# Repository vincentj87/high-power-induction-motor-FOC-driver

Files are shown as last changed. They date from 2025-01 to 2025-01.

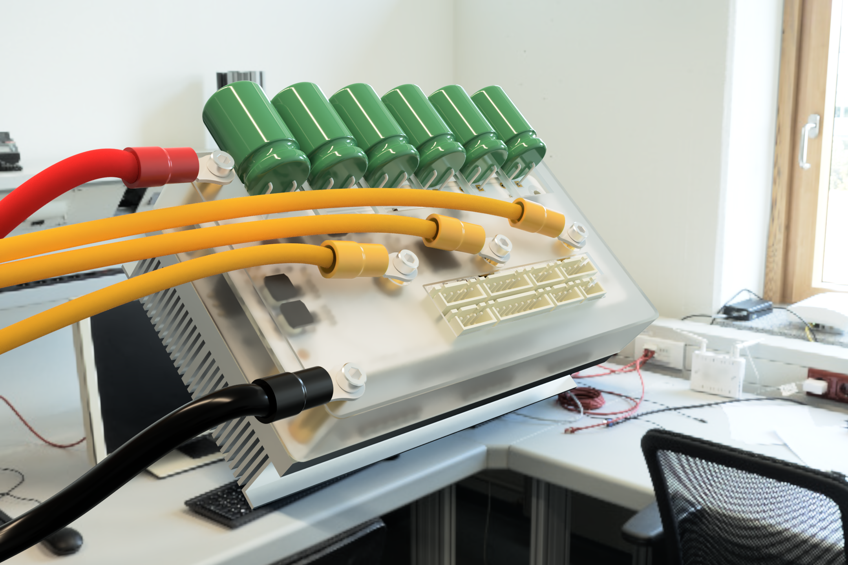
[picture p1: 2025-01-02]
Doc/49a2ab7d-ae84-4829-adb7-912b41497d58.PNG

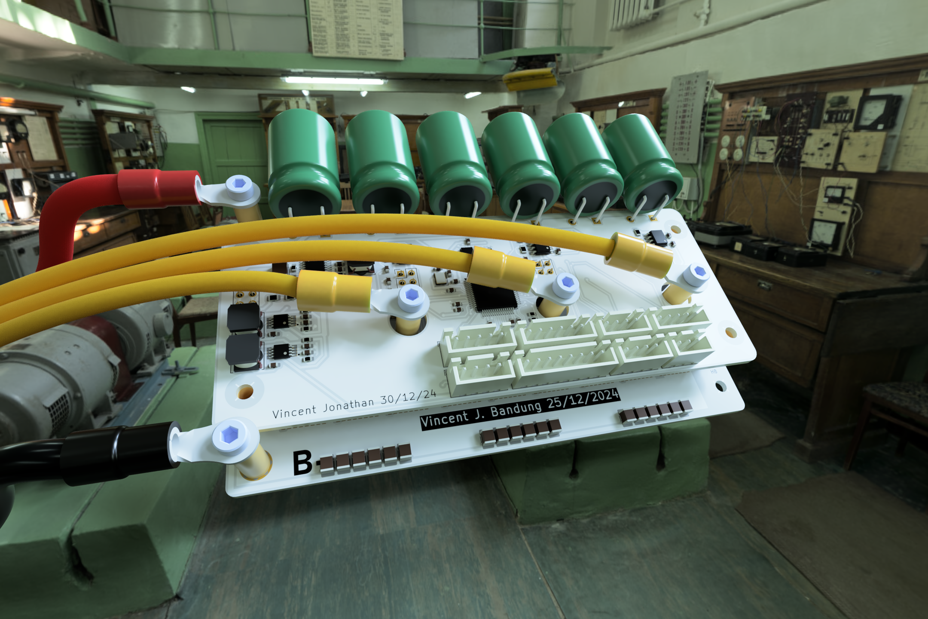
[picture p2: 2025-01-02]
Doc/Untitled_2024-Dec-31_10-01-42AM-000_CustomizedView10278926795.png

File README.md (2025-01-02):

49a2ab7d-ae84-4829-adb7-912b41497d58

# High Power BLDC Motor Driver with Field-Oriented Control (FOC)
This repository contains an ongoing project for a high-power BLDC motor driver, capable of handling up to 92V. The motor driver implements the **Field-Oriented Control (FOC)** commutation method for enhanced efficiency. Additionally, it integrates **Maximum Torque Per Amp (MTPA)** control to optimize performance.

## Key Features:
- **Field-Oriented Control (FOC)**: For efficient commutation, reducing power losses and improving motor performance.
- **MTPA (Maximum Torque Per Amp)**: Optimizes motor operation for maximum torque output with minimal current draw.
- **High Power Handling**: Supports up to 92V for heavy-duty applications.
  
## Components:
All components included in the Bill of Materials (BOM) file are readily available through **LCSC** for easy sourcing.

## PCB Design:
- The controller PCB is designed for a **2-layer FR4** board.
- The MOSFET array is implemented on a **1-layer aluminum PCB** to maximize heat dissipation, particularly under heavy load conditions.

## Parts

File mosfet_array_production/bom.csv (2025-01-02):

Designator | Footprint | Quantity | Value | LCSC Part #
C1, C10, C11, C12, C13, C14, C15, C16, C17, C18, C2, C3, C4, C5, C6, C7, C8, C9 | 1210 | 18 | 4.7uF_100V | C697607
C19, C22, C24 | 0402 | 3 | 2.2uF | C2176814
C20, C21, C23 | 0402 | 3 | 1nF | C106205
H1, H2, H3, H5, H6 | PEM_SMTSO-M3-6ET | 5 | SMTSO-M3-6ET | C30182787
H10, H11, H4, H7 | PEM_SMTSO-M3-6ET | 4 | SMTSO-M3-6ET | C2916370
J1, J2, J3, J4 | PinHeader_2x03_P2.54mm_Vertical_SMD | 4 | header 2x3 | C192301
Q1, Q10, Q11, Q12, Q13, Q14, Q15, Q16, Q17, Q18, Q2, Q3, Q4, Q5, Q6, Q7, Q8, Q9 | Infineon_PG-HSOF-8-1 | 18 | IRLML6244 | C697607
R1, R11, R12, R13, R2, R3, R6, R7, R8 | 2512 | 9 | 0.0005R | C5119469
R4, R5, R9 | 0402 | 3 | 10k | C60490
TH1, TH2, TH3 | 0402 | 3 | Thermistor_NTC | C2689808
U1, U2, U3 | TSSOP-8_4.4x3mm_P0.65mm | 3 | INA240A1PW | C93965

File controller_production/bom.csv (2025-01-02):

Designator | Footprint | Quantity | Value | LCSC Part #
C1, C2 | 0603 | 2 | 20pF | C5137583
C10, C11, C12, C15, C17, C20, C22, C25, C26, C27, C28, C3, C39, C4, C40, C8, C9 | 0603 | 17 | 2.2uf | C2835569
C13, C14, C16, C21, C24, C29, C30, C31, C32, C41, C5 | 0603 | 11 | 100nF | C14663
C18 | 0603 | 1 | 10nF | C100042
C19 | 1812 | 1 | 4.7uF 100V | C2831628
C23 | 0603 | 1 | 22uF_16V | C59461
C33, C36, C38 | 0603 | 3 | 1nF | C342905
C34, C35, C37 | 0603 | 3 | 15nF | C527994
C42, C43, C44, C45, C46, C47 | CP_Radial_D16.0mm_P7.50mm | 6 | 470uF_100V | C365811
C6, C7 | 0603 | 2 | 2.2uf | C2167658
D1, D3 | 0603 | 2 | LED | C3291493
D2 | 0603 | 1 | LED | C496821
J1, J2, J3, J4 | PinHeader_2x03_P2.54mm_Vertical | 4 | Conn_02x03_Odd_Even | C32713304
J10, J11 | JST_XH_B5B-XH-A_1x05_P2.50mm_Vertical | 2 | Conn_01x05 | C157991
J12, J5, J6 | JST_XH_B4B-XH-A_1x04_P2.50mm_Vertical | 3 | Conn_01x04 | C144395
J7 | JST_XH_B6B-XH-A_1x06_P2.50mm_Vertical | 1 | Conn_01x06 | C144397
J8 | JST_XH_B8B-XH-A_1x08_P2.50mm_Vertical | 1 | Conn_01x08 | C157972
J9 | JST_XH_B3B-XH-A_1x03_P2.50mm_Vertical | 1 | Conn_01x03 | C144394
JP1 | SolderJumper-2_P1.3mm_Open_TrianglePad1.0x1.5mm | 1 | DNP | DNP
JP2, JP4, JP5, JP6, JP8 | SolderJumper-2_P1.3mm_Open_TrianglePad1.0x1.5mm | 5 | DNP
JP3 | SolderJumper-2_P1.3mm_Open_TrianglePad1.0x1.5mm | 1 | Jumper_2_Open
L1, L2, L3 | L_TDK_VLS6045EX_VLS6045AF | 3 | 100uH 1A | C2042037
R1 | 0603 | 1 | 402k | C705774
R10, R12, R14, R8 | 0805 | 4 | 56k 0.5W | C441990
R11, R13, R15, R9 | 0805 | 4 | 2.2k | C2078022
R16, R17, R18, R19 | 0603 | 4 | 220R | C351666
R2, R5, R7 | 0603 | 3 | 10k | C98220
R20, R21, R22 | 0603 | 3 | 2.2k | C2078022
R23 | 0603 | 1 | 100R | C855560
R3 | 0603 | 1 | 2k | C103396
R4, R6 | 0603 | 2 | 33k | C163907
U1 | LQFP-64_10x10mm_P0.5mm | 1 | STM32F405RGTx | C15742
U2, U3, U4 | SOIC127P599X175-8N | 3 | UCC27210D | C2871979
U5 | HTSSOP-14-1EP_4.4x5mm_P0.65mm_EP3.4x5mm_Mask3x3.1mm | 1 | LM5161PWP | C468246
U6, U7 | SOP65P490X110-8N | 2 | MCP16311-E_MS | C627024
U8 | DFN-8-1EP_3x3mm_P0.65mm_EP1.55x2.4mm | 1 | TJA1051TK-3 | C2875699
Y1 | Crystal_SMD_3225-4Pin_3.2x2.5mm | 1 | 8Mhz | C5265856

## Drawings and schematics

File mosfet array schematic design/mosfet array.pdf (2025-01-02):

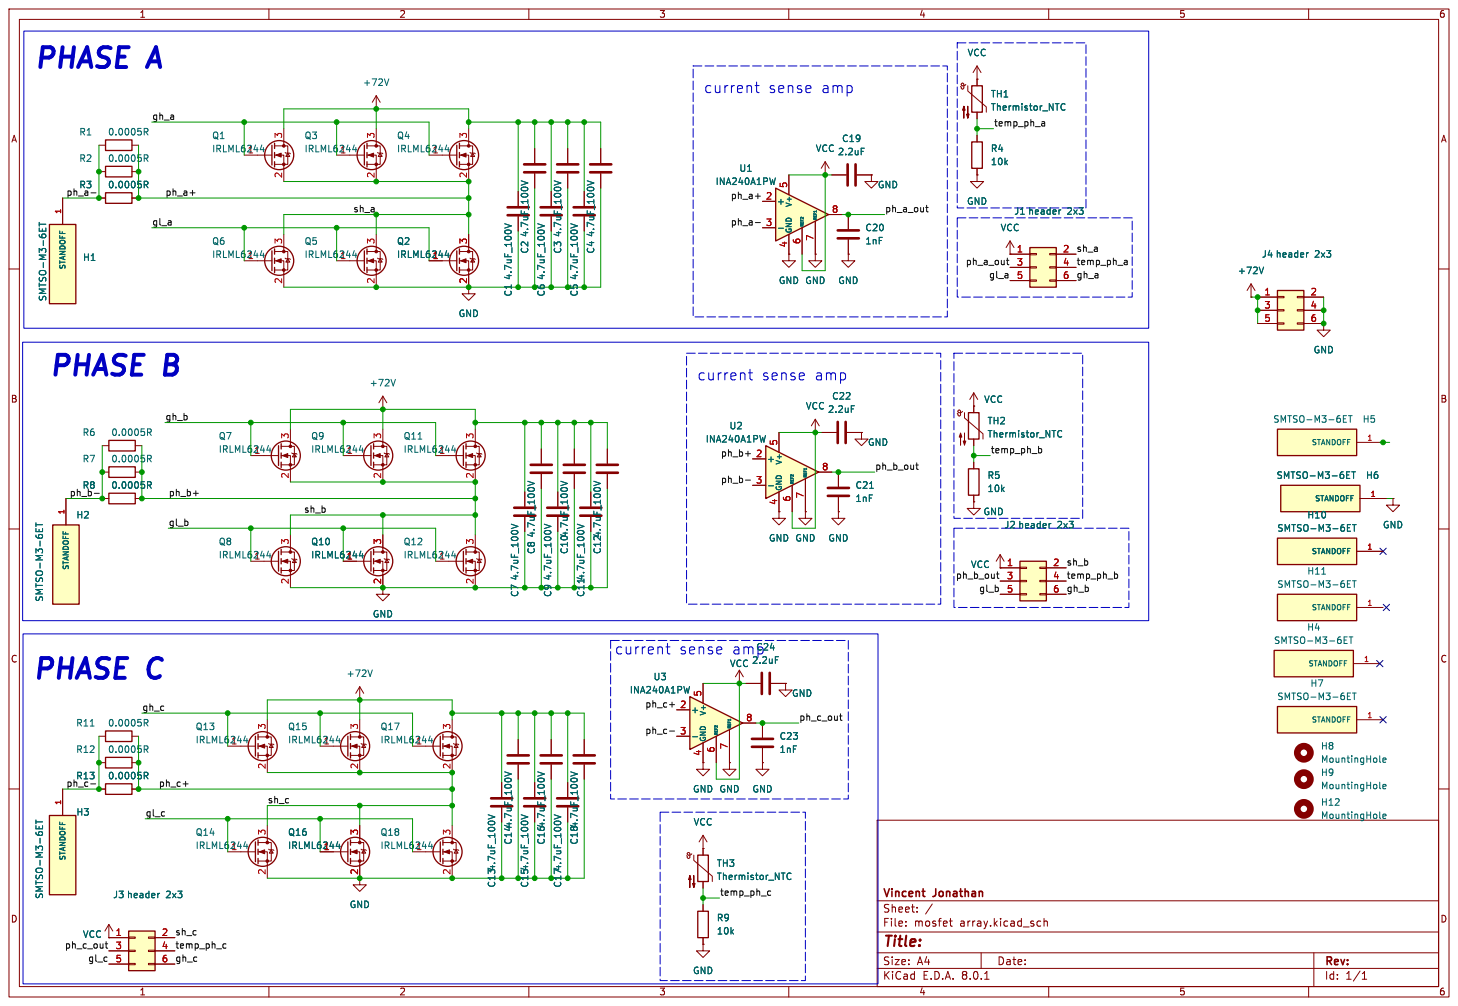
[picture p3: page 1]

+72V GND GND GND GND

Id: 1/1 Title: File: mosfet array.kicad_sch Sheet: / Vincent Jonathan

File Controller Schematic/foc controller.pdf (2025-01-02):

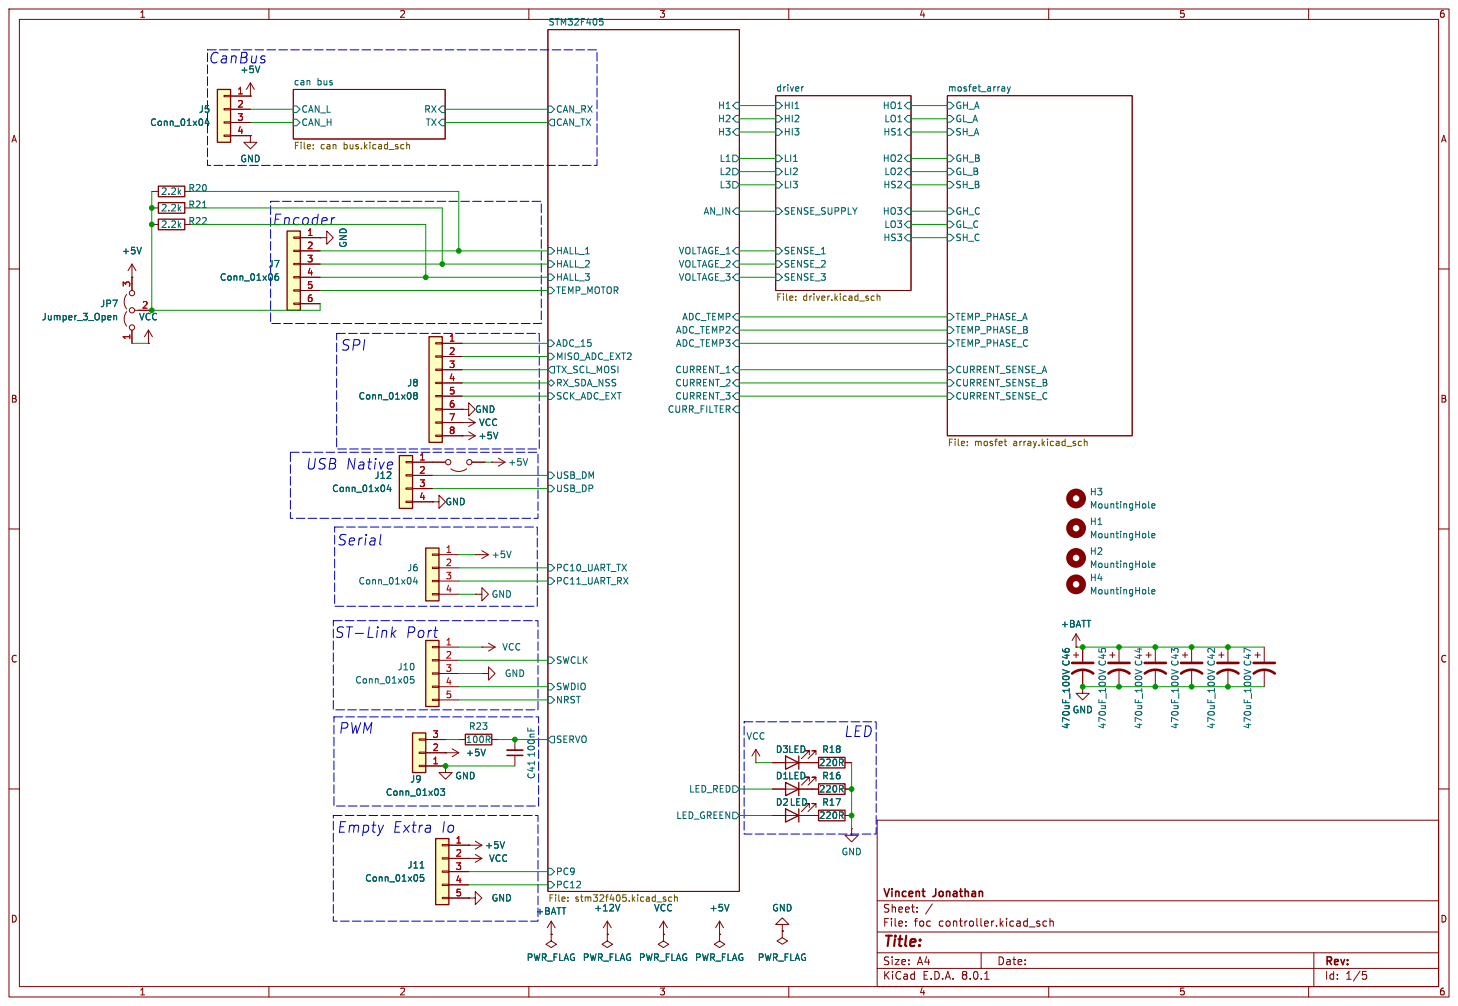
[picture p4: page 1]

Id: 1/5 Title: File: foc controller.kicad_sch Sheet: / Vincent Jonathan

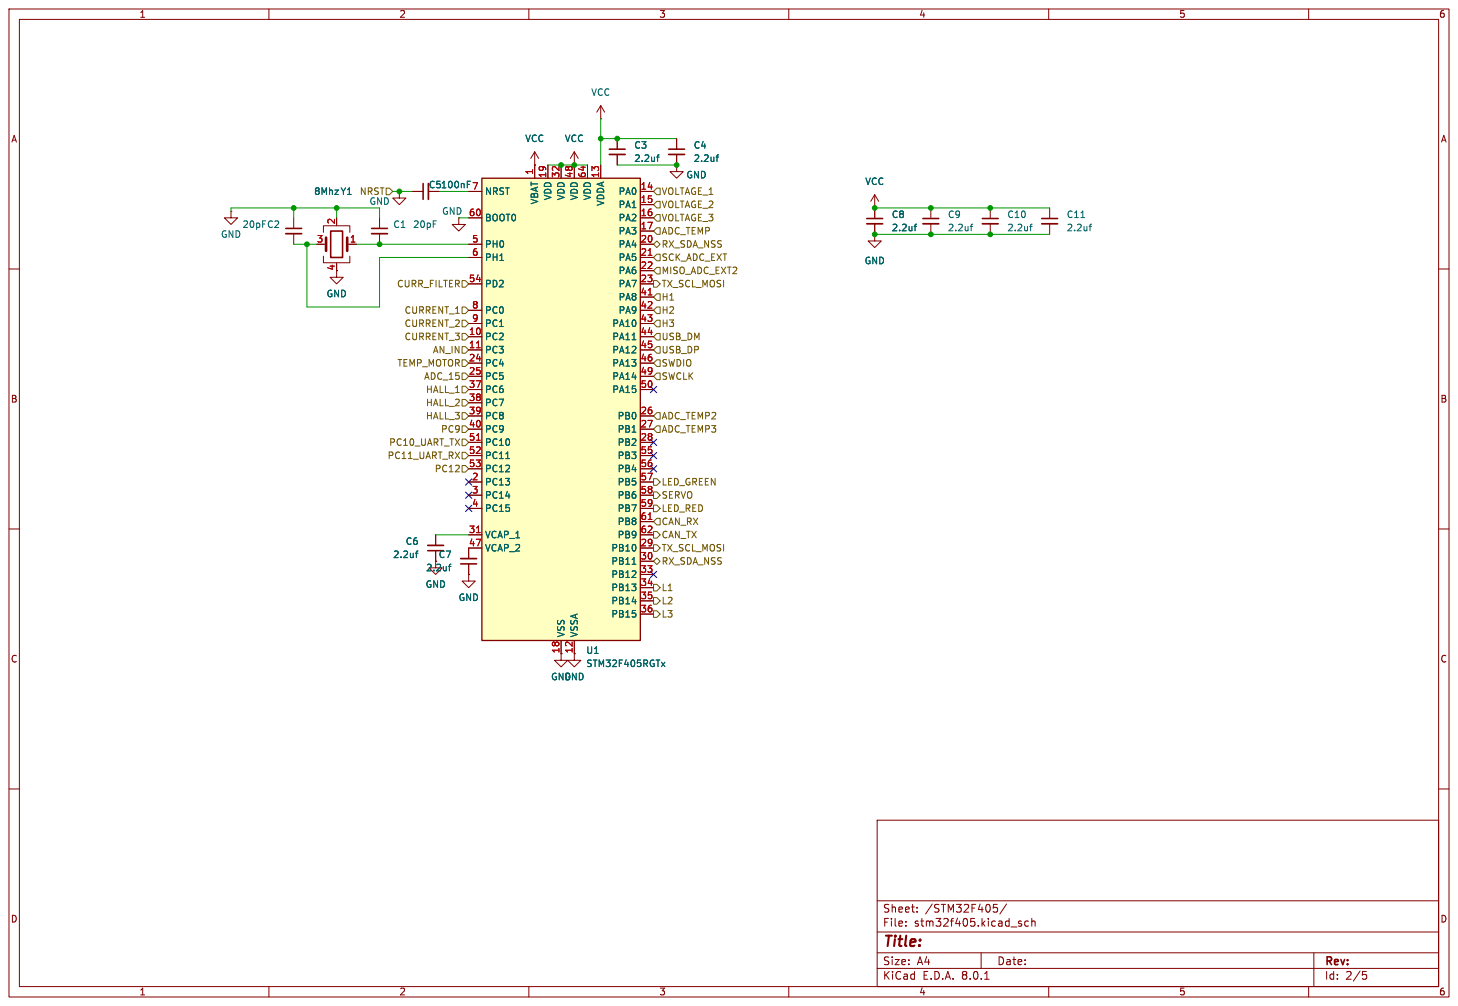
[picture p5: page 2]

Id: 2/5 Title: File: stm32f405.kicad_sch Sheet: /STM32F405/

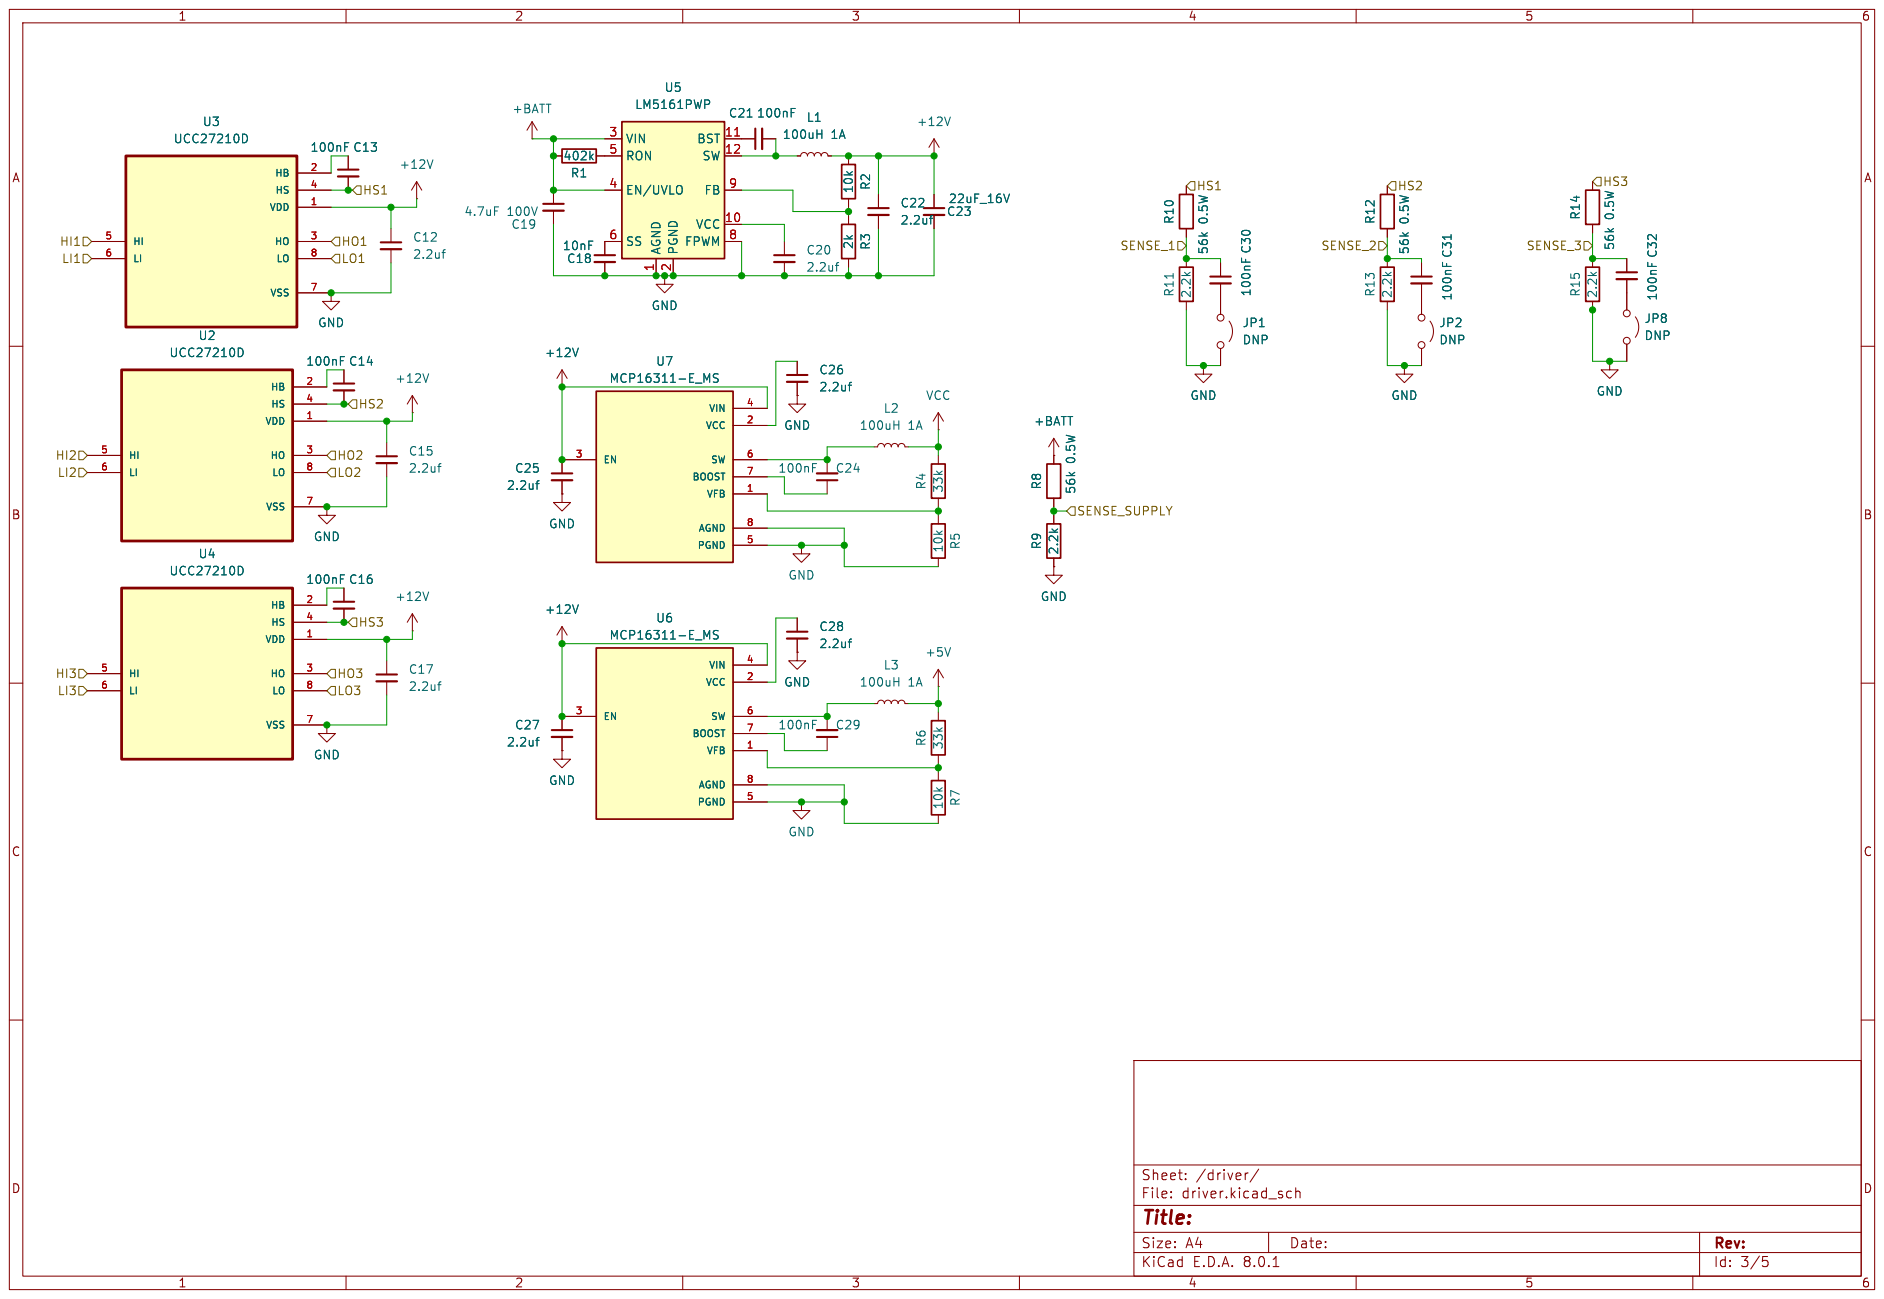
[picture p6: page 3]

2 VIN 3 EN/UVLO 4 RON 5 SS 6 FPWM 8 FB 9 U5
LM5161PWP C27

2 VIN 3 EN/UVLO 4 RON 5 SS 6 FPWM 8 FB 9 C22

1 VCC 10 BST 11 SW 12 PGND

Id: 3/5 Title: File: driver.kicad_sch Sheet: /driver/ GND GND

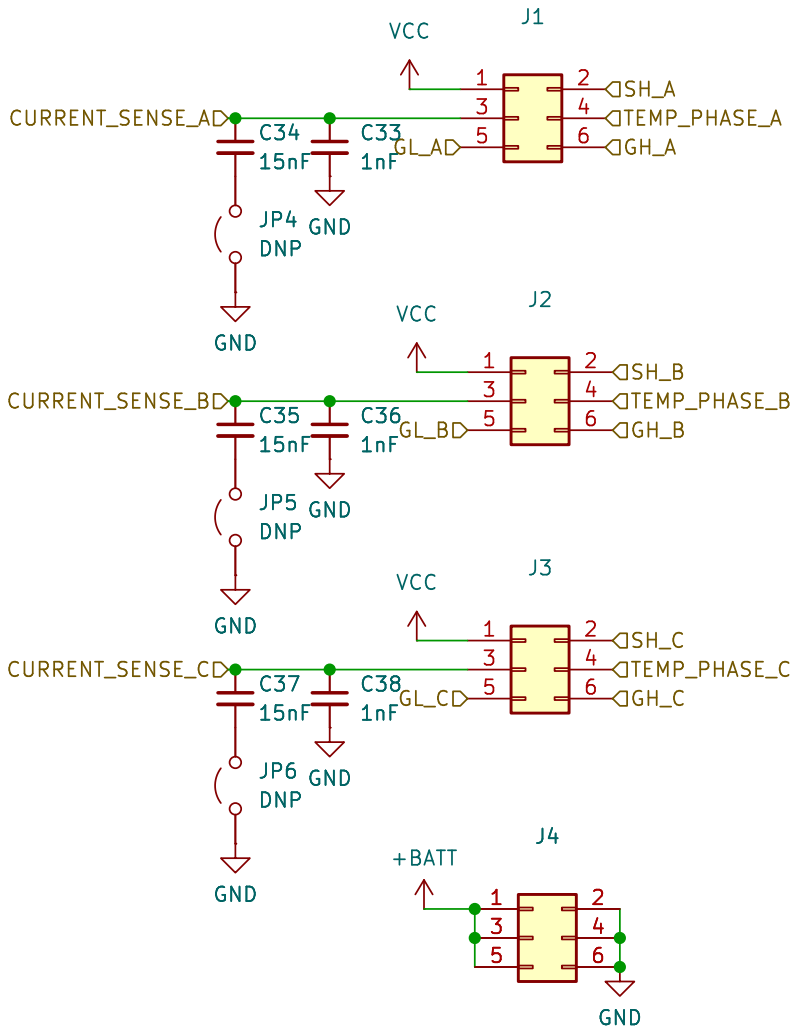
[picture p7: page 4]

Id: 4/5 Title: File: mosfet array.kicad_sch Sheet: /mosfet_array/ C38

3 3 | 4 4

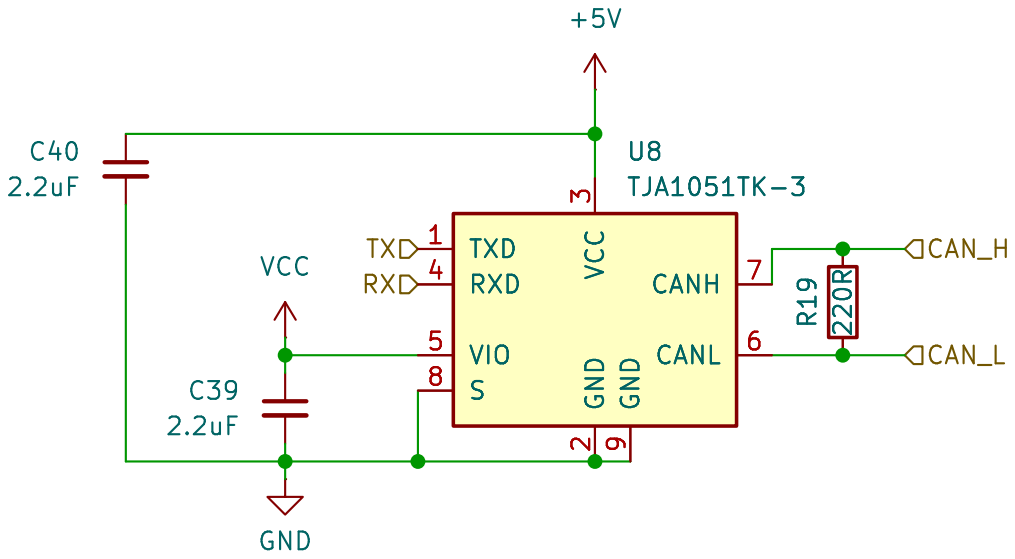
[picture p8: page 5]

3 RXD 4 VIO 5 CANL 6 CANH 7 S
VCC GND

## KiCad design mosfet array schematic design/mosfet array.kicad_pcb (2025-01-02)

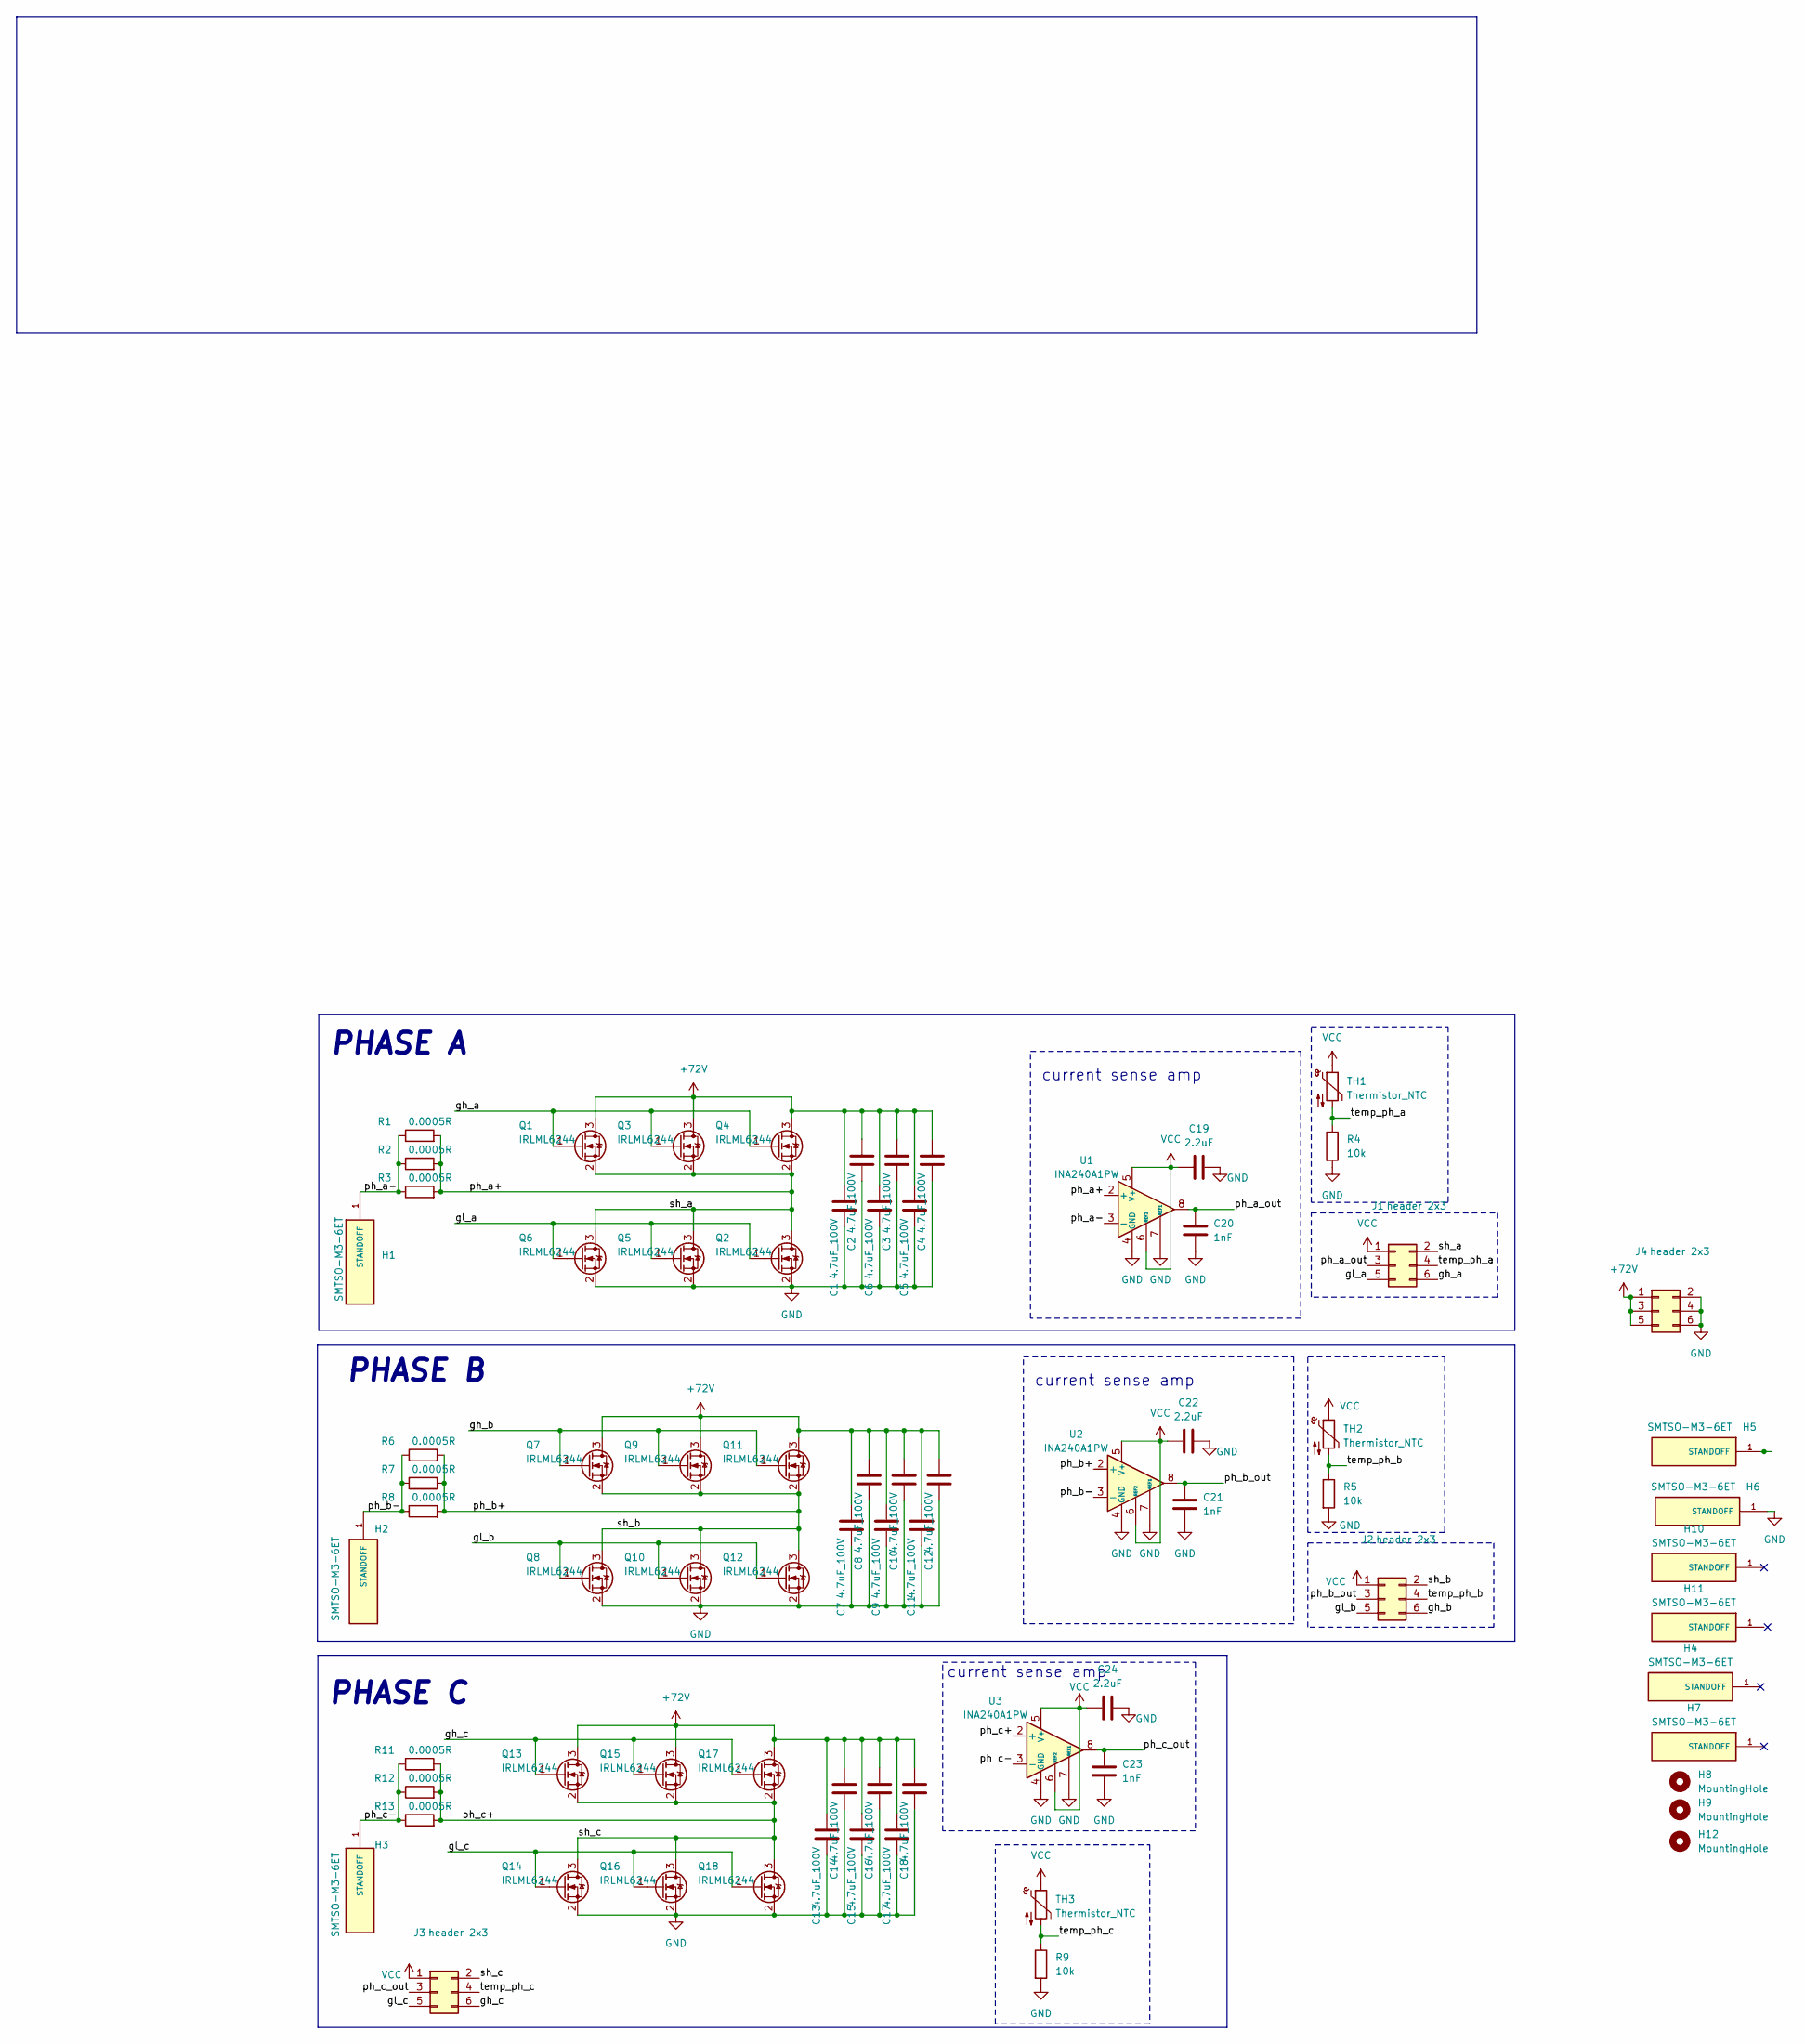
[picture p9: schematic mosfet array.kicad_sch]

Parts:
C1, C2, C3, C4, C5, C6, C7, C8, C9, C10, C11, C12, C13, C14, C15, C16, C17, C18: 4.7uF_100V; C_1210_3225Metric_Pad1.33x2.70mm_HandSolder; LCSC C697607
C19, C22, C24: 2.2uF; C_0402_1005Metric; LCSC C2176814
C20, C21, C23: 1nF; C_0402_1005Metric; LCSC C106205
H1, H2, H3, H5, H6: SMTSO-M3-6ET; PEM_SMTSO-M3-6ET; PARTREV 11/27/23; LCSC C30182787
H4, H7, H10, H11: SMTSO-M3-6ET; PEM_SMTSO-M3-6ET; PARTREV 11/27/23; LCSC C2916370
H8, H9, H12: MountingHole; MountingHole_3.2mm_M3
J1, J2, J3, J4: header 2x3; PinHeader_2x03_P2.54mm_Vertical_SMD; LCSC C192301
Q1, Q2, Q3, Q4, Q5, Q6, Q7, Q8, Q9, Q10, Q11, Q12, Q13, Q14, Q15, Q16, Q17, Q18: IRLML6244; Infineon_PG-HSOF-8-1; LCSC C697607
R1, R2, R3, R6, R7, R8, R11, R12, R13: 0.0005R; R_2512_6332Metric; LCSC C5119469
R4, R5, R9: 10k; R_0402_1005Metric; LCSC C60490
TH1, TH2, TH3: Thermistor_NTC; R_0402_1005Metric; LCSC C2689808
U1, U2, U3: INA240A1PW; TSSOP-8_4.4x3mm_P0.65mm; LCSC C93965

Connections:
+72V: C1.1, C2.1, C3.1, C4.1, C5.1, C6.1, C7.1, C8.1, C9.1, C10.1, C11.1, C12.1, C13.1, C14.1, C15.1, C16.1, C17.1, C18.1, J4.1, J4.3, J4.5, Q1.3 (D), Q3.3 (D), Q4.3 (D), Q7.3 (D), Q9.3 (D), Q11.3 (D), Q13.3 (D), Q15.3 (D), Q17.3 (D)
/gh_a: J1.6, Q1.1 (G), Q3.1 (G), Q4.1 (G)
/gh_b: J2.6, Q7.1 (G), Q9.1 (G), Q11.1 (G)
/gh_c: J3.6, Q13.1 (G), Q15.1 (G), Q17.1 (G)
/gl_a: J1.5, Q2.1 (G), Q5.1 (G), Q6.1 (G)
/gl_b: J2.5, Q8.1 (G), Q10.1 (G), Q12.1 (G)
/gl_c: J3.5, Q14.1 (G), Q16.1 (G), Q18.1 (G)
/ph_a+: J1.2, Q1.2 (S), Q2.3 (D), Q3.2 (S), Q4.2 (S), Q5.3 (D), Q6.3 (D), R1.2, R2.2, R3.2, U1.2 (+)
/ph_a-: H1.1 (STANDOFF), R1.1, R2.1, R3.1, U1.3 (-)
/ph_a_out: C20.2, J1.3, U1.8
/ph_b+: J2.2, Q7.2 (S), Q8.3 (D), Q9.2 (S), Q10.3 (D), Q11.2 (S), Q12.3 (D), R6.2, R7.2, R8.2, U2.2 (+)
/ph_b-: H2.1 (STANDOFF), R6.1, R7.1, R8.1, U2.3 (-)
/ph_b_out: C21.2, J2.3, U2.8
/ph_c+: J3.2, Q13.2 (S), Q14.3 (D), Q15.2 (S), Q16.3 (D), Q17.2 (S), Q18.3 (D), R11.2, R12.2, R13.2, U3.2 (+)
/ph_c-: H3.1 (STANDOFF), R11.1, R12.1, R13.1, U3.3 (-)
/ph_c_out: C23.2, J3.3, U3.8
/temp_ph_a: J1.4, R4.1, TH1.2
/temp_ph_b: J2.4, R5.1, TH2.2
/temp_ph_c: J3.4, R9.1, TH3.2
GND: C1.2, C2.2, C3.2, C4.2, C5.2, C6.2, C7.2, C8.2, C9.2, C10.2, C11.2, C12.2, C13.2, C14.2, C15.2, C16.2, C17.2, C18.2, C19.2, C20.1, C21.1, C22.2, C23.1, C24.2, H6.1 (STANDOFF), J4.2, J4.4, J4.6, Q2.2 (S), Q5.2 (S), Q6.2 (S), Q8.2 (S), Q10.2 (S), Q12.2 (S), Q14.2 (S), Q16.2 (S), Q18.2 (S), R4.2, R5.2, R9.2, U1.1 (GND), U1.4 (GND), U1.7 (REF1), U2.1 (GND), U2.4 (GND), U2.7 (REF1), U3.1 (GND), U3.4 (GND), U3.7 (REF1)
VCC: C19.1, C22.1, C24.1, J1.1, J2.1, J3.1, TH1.1, TH2.1, TH3.1, U1.5 (V+), U1.6 (REF2), U2.5 (V+), U2.6 (REF2), U3.5 (V+), U3.6 (REF2)

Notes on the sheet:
current sense amp
PHASE A
PHASE B
PHASE C

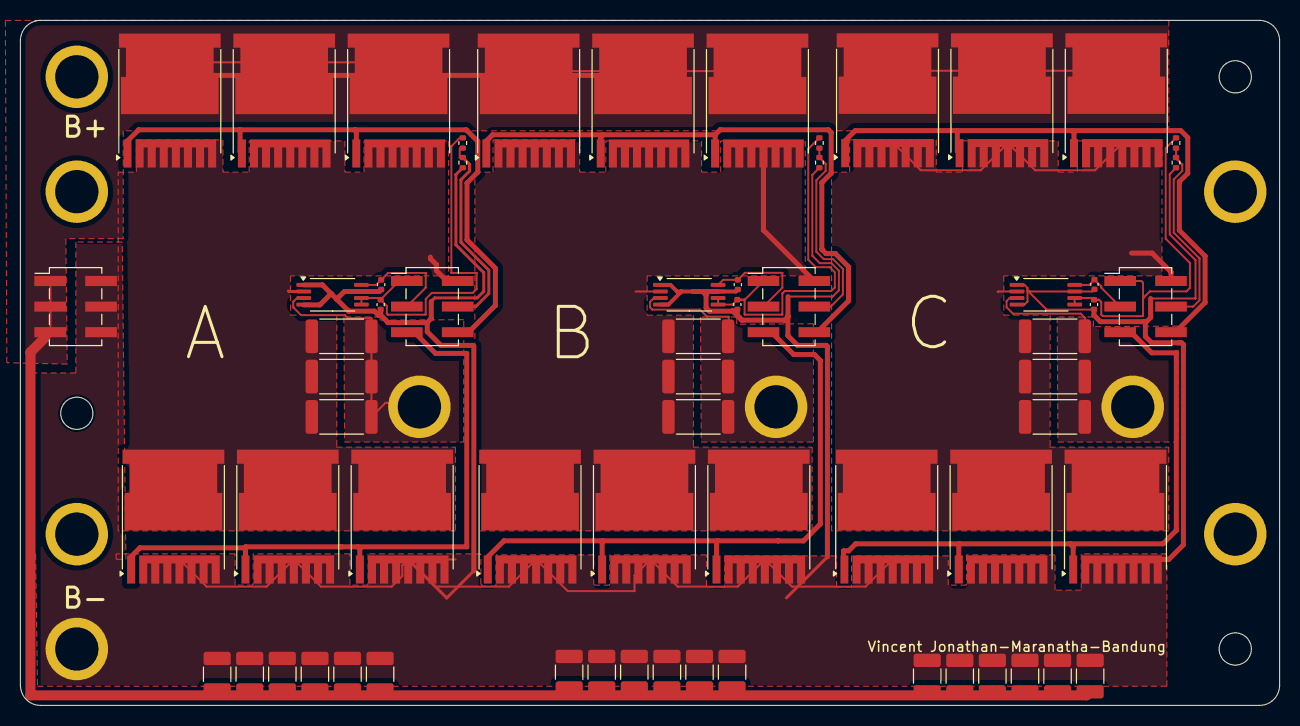
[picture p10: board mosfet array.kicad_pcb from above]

Board: 2 copper layers, 125.0 x 68.0 mm, 76 parts (0 on the bottom side), 21 nets.
